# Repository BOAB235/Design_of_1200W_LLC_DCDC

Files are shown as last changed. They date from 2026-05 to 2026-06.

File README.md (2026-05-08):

<div align="center">

# 1200 W · 400 V → 48 V · LLC Resonant DC-DC Converter

**Open-Source Hardware Design for Electric-Vehicle Auxiliary Power**



<br>

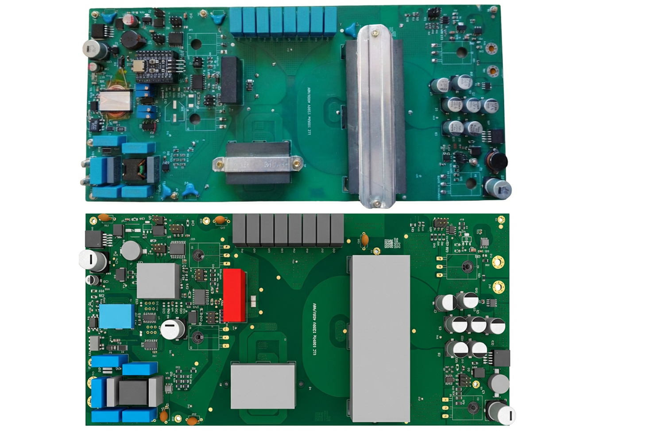
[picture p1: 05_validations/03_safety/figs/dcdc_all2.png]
1200W LLC DC-DC Converter


<br>

*A complete, open-source hardware project — from analytical tank design through PCB fabrication, embedded control firmware, EMC testing, and efficiency characterization — targeting the 400 V traction bus to 48 V auxiliary rail conversion found in modern electric vehicles.*

<br>

[**Interactive Project Page & Gallery**](https://boab235.github.io/pages/llc/llc.html)

</div>

---

## Table of Contents

- [Context & Motivation](#context--motivation)
- [Key Specifications](#key-specifications)
- [Repository Map](#repository-map)
- [Hardware Design](#hardware-design)
  - [LLC Resonant Tank](#llc-resonant-tank)
  - [Planar Magnetics](#planar-magnetics)
  - [Power MOSFETs](#power-mosfets)
  - [Capacitor Bank](#capacitor-bank)
  - [EMI Filter (CISPR 25)](#emi-filter-cispr-25)
  - [Gate Driver & HW Protection](#gate-driver--hw-protection)
  - [Thermal Management](#thermal-management)
  - [Schematic, PCB & BOM](#schematic-pcb--bom)
- [Embedded Firmware](#embedded-firmware)
- [Validation & Testing](#validation--testing)
- [Tools & Technologies](#tools--technologies)
- [Getting Started](#getting-started)
- [Project Page](#project-page)
- [License](#license)

---

## Context & Motivation

In battery electric vehicles (BEVs) and 48 V mild-hybrid architectures, a **high-voltage DC-DC converter** steps the 300–400 V traction battery bus down to the 48 V auxiliary rail that powers lighting, HVAC blowers, infotainment, ADAS sensors, and body-control electronics. The LLC resonant topology is the industry-preferred choice for this role because it naturally achieves **zero-voltage switching (ZVS)** across the load range, yielding high efficiency, low EMI, and compact magnetics.

This project documents the **complete physical design** of such a converter:

1. **Analytical Design** — Resonant tank optimisation, magnetic core selection, MOSFET thermal analysis, EMI filter sizing, and PCB trace calculations — all in reproducible Jupyter notebooks.
2. **Hardware Build** — KiCad schematic (V5), BOM, Gerber files, and a custom PCB with planar magnetics.
3. **Embedded Control** — 23 iterative firmware versions on an STM32F103C8T6, culminating in an adaptive PI controller with thermal derating (bare-metal C/C++, register-level).
4. **Test & Characterisation** — EMC conducted-emissions testing (CISPR 25 setup), safety tests, LLC gain & tank characterisation, and full-load efficiency measurements.

> **Note:** This is primarily a **hardware/power-electronics project**. The firmware is a supporting element written in embedded C++ on an STM32 to close the voltage-regulation loop — it is not a software product.

---

## Key Specifications

| Parameter | Value |
| --- | --- |
| **Topology** | Half-bridge LLC resonant (isolated) |
| **Input voltage** | 360 – 400 V DC (traction battery bus) |
| **Output voltage** | 42 – 54 V DC (nominal 48 V) |
| **Rated output power**  | 1 200 W continuous |
| **Rated output current**| 25 A nominal |
| **Switching frequency** | 95 – 150 kHz (nominal ≈ 100 kHz) |
| **Transformer ratio** | n = 4 |
| **Efficiency target** | ≥ 95 % at nominal load |
| **Output voltage ripple** | < 250 mV pp |
| **Primary MOSFETs** | 2 × IPW60R037CM8 (600 V, 3.7 mΩ) |
| **Secondary MOSFETs** | 2 × FDH055N15A (150 V, 110 A) |
| **Output capacitors** | 6 × 120 µF (B40910A8127M000) |
| **Gate driver** | UCC21520Q |
| **MCU** | STM32F103C8T6 (Cortex-M3, 72 MHz) |
| **Dead time** | ≈ 100 ns (DTG register, configurable) |
| **EMI standard** | CISPR 25 conducted-emissions setup |
| **PCB revision** | V5 (latest) |

---

## Repository Map

```
Design_of_1200W_LLC_DCDC/
│
├── 01_specifications/              ← System-level specification (see companion spec document)
├── 02_architecture/                ← High-level converter architecture & block diagrams
│
├── 03_hw_design/                   ── HARDWARE ──────────────────────────────────
│   ├── 01_design_justification/    ← Parametric calculations & Jupyter notebooks
│   │   ├── 01_llc_tank/                  Resonant tank (Lr, Cr, Lm, Q, fn curves)
│   │   ├── 01_transformer_and_Lr_cores/  Core selection (TDK N97 planar ferrite)
│   │   ├── 02_mosfets/                   MOSFET thermal & switching-loss analysis
│   │   ├── 03_resonant_and_output_capacitor/  Ripple, ESR, RMS current stress
│   │   ├── 04_measurements/              Sensor calibration (ADC ↔ voltage)
│   │   ├── 05_gate_driver/               Bootstrap & level-shift design
│   │   ├── 06_emi_filters/               CM choke, X/Y caps, damper network
│   │   ├── 07_power_supp/                Auxiliary flyback & LM2575 supplies
│   │   ├── 08_HeatSink/                  Heat-sink thermal-resistance sizing
│   │   ├── 09_Hw_protection/             OVP / OCP via 74HC74 flip-flop logic
│   │   └── 10_cb_calculations/           Trace width, via current, creepage
│   ├── 02_schematic_and_bom/       ← KiCad schematics, Gerbers, BOM
│   └── 03_components/              ← Datasheet library (129 parts)
│
├── 04_sw_design/                   ── EMBEDDED FIRMWARE ─────────────────────────
│   ├── 01_investigations/              STM32 & ESP32 bring-up tests
│   ├── 04_PWM_Freq_Change/             Switching-frequency modulation trials
│   ├── 05_Analog_ADC/                  ADC acquisition & serial logging
│   ├── 06_Analog_ADC_TempInterp*/      Thermistor interpolation (V1 – V4)
│   ├── CONTROL/                        Control firmware archive (V1 – V21)
│   ├── new_control/                    Latest firmware (V22 – V23, adaptive PI)
│   └── soft_start/                     Soft-start sequence analysis
│
├── 05_validations/                 ── TESTING & VALIDATION ──────────────────────
│   ├── 02_emc/                         CISPR 25 conducted-emissions measurement
│   ├── 03_safety/                      Insulation & capacitor-discharge tests
│   ├── 04_driver_test/                 Gate-driver bootstrap & dead-time check
│   ├── 05_Gain_and_LLC_Tank_charac/    LLC gain curves & Lr/Lm measurement
│   ├── 06_Fly_Back/                    Auxiliary flyback converter validation
│   ├── 07_IP_controller/              Controller transient & stability tests
│   ├── 07_Prim_sec_capa/              Primary/secondary capacitor validation
│   ├── 09_LLC_Efficiency/             Full-load efficiency & loss breakdown
│   ├── 10_Buck_converter/             Auxiliary buck converter testing
│   ├── 11_HwProtection/              OCP/OVP trip-point characterisation
│   ├── 12_Divers/                     Miscellaneous characterisation
│   └── soft_start/                    Startup-waveform capture
│
├── 99_archive/                     ← Legacy code & utility scripts
└── to_be_orgnized/                 ← Draft simulations & preliminary work
```

---

## Hardware Design

Every design choice is **justified with reproducible calculations** in Jupyter notebooks, supported by LTspice simulations and component datasheets.

### LLC Resonant Tank

The resonant-tank parameters — resonant frequency $f_0$, inductance ratio $L_n = L_m / L_r$, quality factor $Q$ — were optimised to deliver the required voltage gain $M_g$ across the full 360–400 V input range while maintaining ZVS down to light load.

$$M_g = \left| \frac{L_n \cdot f_n^2}{\left[(L_n + 1) f_n^2 - 1\right] + j\left[(f_n^2 - 1) f_n Q_e L_n\right]} \right|$$

> **Notebook:** [`03_hw_design/01_design_justification/01_llc_tank/`](03_hw_design/01_design_justification/01_llc_tank/)
>
> **PDF report:** [LLC Tank Design Note](https://boab235.github.io/pages/llc/pdfs/01_LLC_48v_LLC_tank_design_note_v2.pdf)

### Planar Magnetics

Both the main transformer ($L_m ≈ 65 \text{ µH}$) and the resonant inductor ($L_r$) use **TDK N97** planar ferrite cores, chosen for low core-loss density at 100 kHz and excellent thermal conductivity. Transformer turns ratio is $n = V_{in,nom}/(2 \times V_{o,nom}) = 380/96 ≈ 4$.

> **Notebook:** [`03_hw_design/01_design_justification/01_transformer_and_Lr_cores/`](03_hw_design/01_design_justification/01_transformer_and_Lr_cores/)
>
> **PDF report:** [Magnetic Cores Design](https://boab235.github.io/pages/llc/pdfs/01_LLC_48v_LLC_Magnetic_Cores_V3.pdf)

### Power MOSFETs

| Side | Device | Rating | $R_{DS(on)}$ | Package |
|---|---|---|---|---|
| **Primary** (half-bridge) | IPW60R037CM8XKSA1 | 600 V / 60 A | 3.7 mΩ | TO-247 |
| **Secondary** (sync. rect.) | FDH055N15A | 150 V / 110 A | low | TO-247 |

ZVS dead-time requirement: $t_{dead} \geq 16 \cdot C_{eq} \cdot f_{sw} \cdot L_m$ — set to ≈ 100 ns with margin.

> **Notebook:** [`03_hw_design/01_design_justification/02_mosfets/`](03_hw_design/01_design_justification/02_mosfets/)

### Capacitor Bank

Six **B40910A8127M000** (120 µF, 150 °C rated aluminium electrolytic) capacitors in parallel:

- **Total capacitance:** ≥ 576 µF (with 20 % worst-case derating)
- **Equivalent ESR @ 100 kHz:** 17 mΩ / 6 ≈ 2.8 mΩ (< 3.18 mΩ target)
- **Output ripple budget:** < 250 mV pp (50 % capacitive + 50 % resistive split)

> **Notebook:** [`03_hw_design/01_design_justification/03_resonant_and_output_capacitor/`](03_hw_design/01_design_justification/03_resonant_and_output_capacitor/)
>
> **PDF report:** [Output Capacitor Design](https://boab235.github.io/pages/llc/pdfs/03_LLC_48v_LLC_output_capa_v4.pdf)

### EMI Filter (CISPR 25)

Two-stage common-mode / differential-mode filter designed for automotive conducted-emissions compliance:

| Component | Value | Role |
| --- | --- | --- |
| CM choke | PA2750NL (400 µH)  | CM noise attenuation  |
| Y capacitors | 4 × 2.2 nF | CM return path |
| X capacitor | 100 nF | DM filtering |
| Damper network | 27 Ω + 2.2 nF | Resonance suppression |

- **CM resonant frequency:** ≈ 170 kHz
- **DM LC cut-off:** ≈ 425 kHz
- **Leakage inductance (DM):** 1.4 µH

> **Design report:** [`03_hw_design/01_design_justification/06_emi_filters/justification.md`](03_hw_design/01_design_justification/06_emi_filters/justification.md)

### Gate Driver & HW Protection

- **Gate driver IC:** UCC21520Q with bootstrap supply for high-side drive.
- **Fast hardware protection:** 74HC74 D flip-flop latches OVP/OCP faults and disables PWM within nanoseconds — independent of firmware response time.
- **Voltage/current sensing:** Resistive dividers and ACS70331 current sensor, calibrated against 12-bit ADC ($V_{out} = 0.03081 \times ADC - 0.0976$).

> **Design files:** [`05_gate_driver/`](03_hw_design/01_design_justification/05_gate_driver/) · [`09_Hw_protection/`](03_hw_design/01_design_justification/09_Hw_protection/)

### Thermal Management

Heat-sink thermal resistance sized for worst-case junction temperature of primary TO-247 MOSFETs at full 1 200 W load, with forced-air fan controlled via TIM2 PWM on the STM32.

> **Notebook:** [`03_hw_design/01_design_justification/08_HeatSink/`](03_hw_design/01_design_justification/08_HeatSink/)

### Schematic, PCB & BOM

Designed in **KiCad**. Trace widths and via counts calculated for 25 A output current with 0.5 oz – 2 oz copper options evaluated.

| Document | Link |
| --- | ---- |
| **Schematic (PDF)** | [LLC_DCDC_V5](https://boab235.github.io/pages/llc/pdfs/LLC_DCDC_V5.pdf) |
| **Gerber & Layout** | [Gerber PDF](https://boab235.github.io/pages/llc/pdfs/LLC_DCDC_V5_Gerber_and_layout.pdf) |
| **Bill of Materials** | [BOM PDF](https://boab235.github.io/pages/llc/pdfs/LLC_DCDC_V5_BOM.pdf) |
| **Modifications log** | [Modifications PDF](https://boab235.github.io/pages/llc/pdfs/LLC_DCDC_V5_Modifications.pdf) |

> **Source files:** [`03_hw_design/02_schematic_and_bom/`](03_hw_design/02_schematic_and_bom/)

---

## Embedded Firmware

> The firmware is a **supporting element** of the hardware design — embedded C++ on an STM32, bare-metal (no HAL, no RTOS), for deterministic real-time PWM and ADC control.

```
STM32F103C8T6 @ 72 MHz
├── TIM1_CH2  (PA9)  → High-side gate drive
├── TIM1_CH2N (PB14) → Low-side gate drive   (dead-time DTG ≈ 100 ns)
├── ADC1 (PA0–PA7)   ← Vin, Vout, Isense, Temp
├── GPIO (PB10/12)   → 74HC74 flip-flop enable / reset
├── TIM2 (PA10)      → Fan PWM
└── UART (CH340)     → Serial telemetry @ 115 200 baud
```

**Control evolution (23 versions):**

| Phase | Versions | Strategy |
|---|---|---|
| Open loop | V1 – V11 | Fixed-frequency switching |
| Closed loop PI | V12 – V16 | PI voltage regulation |
| Variable frequency | V17 – V19 | Period-based frequency modulation |
| IP controller | V20 – V21 | Alternative control topology |
| **Adaptive PI** | **V22 – V23** | **Adaptive step-delay + thermal derating** |

The latest firmware (`PI_V23_adaptive_step_delay_derating`) implements proportional-integral voltage regulation, adaptive step-delay for transient optimisation, thermal derating at elevated temperatures, and a controlled soft-start frequency ramp.

> **Latest firmware:** [`04_sw_design/new_control/PI_V23_adaptive_step_delay_derating/`](04_sw_design/new_control/PI_V23_adaptive_step_delay_derating/)
>
> **Full archive (V1 – V21):** [`04_sw_design/CONTROL/`](04_sw_design/CONTROL/)

---

## Validation & Testing

A 12-category validation campaign was carried out on the physical converter:

### System-Level Tests

| Test | Description | Report |
|---|---|---|
| **EMC (CISPR 25)** | Conducted emissions via LISN | [PDF](https://boab235.github.io/pages/llc/pdfs/EMC_Conducted_Emissions_Test_V4.pdf) |
| **Efficiency** | Full-load mapping & loss breakdown | [PDF](https://boab235.github.io/pages/llc/pdfs/LLC_1200W_Efficiency_test.pdf) |
| **Safety** | Capacitor discharge & insulation | [PDF](https://boab235.github.io/pages/llc/pdfs/LLC_Safety_tests_V0.pdf) |

### Subsystem-Level Tests

| Test | Description | Location |
|---|---|---|
| **LLC gain & tank** | Frequency response, Lr/Lm measurement (4 methods) | [PDF](https://boab235.github.io/pages/llc/pdfs/Gain_and_tank_characterization_V0.pdf) |
| **Gate driver** | Bootstrap transient & dead-time verification | [`05_validations/04_driver_test/`](05_validations/04_driver_test/) |
| **Controller stability** | PI transient response & stability | [`05_validations/07_IP_controller/`](05_validations/07_IP_controller/) |
| **HW protection** | OCP/OVP trip-point characterisation | [`05_validations/11_HwProtection/`](05_validations/11_HwProtection/) |
| **Soft-start** | Inrush current & startup waveforms | [`05_validations/soft_start/`](05_validations/soft_start/) |

> **All test data:** [`05_validations/`](05_validations/)

---

## Tools & Technologies

| Category | Tools |
|---|---|
| **Schematic & PCB** | KiCad |
| **Circuit simulation** | LTspice |
| **Design calculations** | Python 3 · Jupyter · NumPy · SciPy · Matplotlib · handcalcs |
| **Firmware** | Arduino IDE + STM32duino core (bare-metal register access) |
| **MCU** | STM32F103C8T6 (primary) · ESP32 (evaluated) |
| **USB-UART** | CH340 @ 115 200 baud |
| **Data analysis** | Pandas · Matplotlib |
| **PCB fabrication** | JLCPCB / PCBWay |

---

## Getting Started

### Browsing the Design

1. Read the [**Specification**](01_specifications/LLC_1200W_SPECIFICATION.md) to understand the top-level requirements.
2. Open the [**LLC Tank Design Notebook**](03_hw_design/01_design_justification/01_llc_tank/01_LLC_48v_LLC_tank_design_note_v2.ipynb) for resonant-converter theory and parameter selection.
3. Review the [**Schematic (PDF)**](https://boab235.github.io/pages/llc/pdfs/LLC_DCDC_V5.pdf) for the complete circuit.
4. Check the [**BOM**](https://boab235.github.io/pages/llc/pdfs/LLC_DCDC_V5_BOM.pdf) for component sourcing.

### Building the Firmware

1. Install [Arduino IDE](https://www.arduino.cc/en/software) with the **STM32duino** board package.
2. Select board: **Generic STM32F1 series → STM32F103C8**.
3. Open `04_sw_design/new_control/PI_V23_adaptive_step_delay_derating/PI_V23_adaptive_step_delay_derating.ino`.
4. Connect the STM32 Blue Pill via ST-Link or USB-to-Serial (CH340).
5. Compile and upload.

### Reproducing the Notebooks

```bash
pip install jupyter numpy scipy matplotlib handcalcs
jupyter notebook
```

Open any `.ipynb` file in `03_hw_design/01_design_justification/`.

---

## Project Page

An interactive project page with documentation, downloadable PDFs, and a photo gallery:

**[https://boab235.github.io/pages/llc/llc.html](https://boab235.github.io/pages/llc/llc.html)**

---

## License

This project is open-source under the MIT License. See the repository for details.

<div align="center">

**[Report an Issue](https://github.com/BOAB235/Design_of_1200W_LLC_DCDC/issues) · [Project Page](https://boab235.github.io/pages/llc/llc.html) · [GitHub](https://github.com/BOAB235/Design_of_1200W_LLC_DCDC)**

</div>

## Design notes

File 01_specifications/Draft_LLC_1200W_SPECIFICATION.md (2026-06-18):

# Specification — 1200 W LLC Resonant DC-DC Converter

| Field | Value |
| --- | --- |
| **Document ID** | SPEC-LLC1200-001 |
| **Revision** | A |
| **Date** | 2026-04-02 |
| **Status** | Released |
| **Author** | — |

---

## 1. Purpose & Scope

This document defines the electrical, mechanical, environmental, and functional requirements for a **1 200 W isolated DC-DC converter** that steps the high-voltage traction-battery bus of an electric vehicle down to the 48 V auxiliary rail. It covers the converter as a standalone assembly (power board + control board) and does not cover the vehicle-level wiring harness or battery-management system interface.

---

## 2. System Context

```
┌──────────────┐          ┌─────────────────────┐          ┌──────────────┐
│  HV Traction │  360-400 │   1200 W LLC DC-DC  │  42-54 V │  48 V Aux    │
│  Battery     │───V DC──▶│   Converter          │────DC───▶│  Bus (loads) │
│  (≈ 96S Li)  │          │   (this product)     │          │              │
└──────────────┘          └─────────────────────┘          └──────────────┘
                                    │
                                    │ UART telemetry (debug)
                                    ▼
                              Host / Logger
```

**Typical 48 V loads in an EV:** electric power steering, HVAC blower, headlamps (LED matrix), infotainment head-unit, ADAS radar/camera, body-control modules, seat heaters, DC-DC pre-charge relay coils.

---

## 3. Applicable Standards & References

| Standard / Document | Relevance |
| --- | --- |
| **CISPR 25** (Ed. 5)  | Conducted & radiated emissions limits for vehicles |
| **ISO 16750-2** | Road vehicles — Environmental conditions — Electrical loads |
| **ISO 16750-4** | Road vehicles — Environmental conditions — Climatic loads |
| **IEC 60664-1** | Insulation coordination — Creepage & clearance |
| **IEC 61558-2-16** | Safety of power transformers for switch-mode power supplies |
| **LV 124** (OEM ref.) | Electrical & environmental requirements for automotive components |
| **AEC-Q101** | Qualification of discrete semiconductors (MOSFET reliability) |

> *Note — Full standard compliance is a design target; formal certification is outside the scope of this open-source project.*

---

## 4. Electrical Specifications

### 4.1 Input (High-Voltage Side)

| Parameter | Min | Nom | Max | Unit | Remark |
| --- | --- | --- | --- | ---- | --- |
| Input voltage | 360 | 380 | 400 | V DC | Traction battery range (≈ 96S Li-ion) |
| Input surge (< 1 s) | — | — | 420 | V DC | Transient per ISO 16750-2 |
| Input current (steady-state) | — | 3.3 | 3.6 | A DC | At rated load and η ≥ 95 % |
| Input under-voltage lockout  | 340 | — | — | V DC | Converter shuts down safely |

### 4.2 Output (Low-Voltage Side)

| Parameter | Min | Nom | Max | Unit | Remark |
| --- | --- | ----- | ----- | ---- | --- |
| Output voltage (regulated) | 42  | 48 | 54 | V DC | Covers 48 V Li-ion charge profile |
| Output voltage accuracy | — | — | ±3 | % | Steady-state at 25 °C |
| Output voltage ripple (pk-pk) | — | — | 250 | mV | At full load, 100 kHz BW |
| Output current (continuous) | 0 | 25 | 28 | A | 110 % overload for < 60 s |
| Output power (continuous) | — | 1 200 | — | W | |
| Output power (overload, 60 s) | — | — | 1 320 | W | Thermal derating may apply |
| Transient response (50–100 % load step) | — | — | 5 | % V  | Peak excursion, recovery < 5 ms |

### 4.3 Efficiency

| Condition | Min | Typ | Unit |
| --- | --- | --- | ---- |
| 100 % load, V_in = 380 V, T_amb = 25 °C | 94  | 95  | % |
| 50 % load, V_in = 380 V, T_amb = 25 °C  | 93  | 95  | % |
| 25 % load | 88  | 91  | % |

### 4.4 Isolation

| Parameter | Value | Unit | Remark |
| --- | ----- | ---- | --- |
| Galvanic isolation | Yes | — | Primary-to-secondary transformer |
| Hi-pot test (type test, 1 min)  | 2 500 | V AC | Primary ↔ secondary |
| Working isolation voltage | 800 | V pk | Per IEC 60664-1 |
| Creepage (primary ↔ secondary)  | ≥ 8 | mm | On PCB, per pollution degree 2 |
| Clearance (primary ↔ secondary) | ≥ 5.5 | mm | |

---

## 5. Functional Requirements

### 5.1 Topology

Half-bridge **LLC series-resonant** converter with synchronous rectification on the secondary. Frequency-modulated control at near-50 % duty cycle to maintain ZVS across the operating range.

### 5.2 Resonant Tank

| Parameter | Value | Unit |
| --- | --- | ---- |
| Resonant frequency ($f_0$) | ≈ 100 | kHz  |
| Magnetising inductance ($L_m$) | ≈ 65 | µH |
| Transformer turns ratio ($n$) | 4:1 | — |
| Switching frequency range | 95 – 150 | kHz  |
| Inductance ratio ($L_n = L_m / L_r$) | per design notebook | — |

### 5.3 Control

| Feature | Requirement |
| --- | --- |
| Regulation method | Digital PI (proportional-integral) frequency control |
| Regulation loop bandwidth | > 1 kHz |
| ADC sampling | 12-bit, 8-channel, ≈ 60 kHz loop rate |
| Soft-start | Frequency ramp from f_max → f_nom, limiting inrush |
| Thermal derating | Automatic power roll-back when heat-sink T > threshold |
| Dead-time | Configurable via DTG register, nominal ≈ 100 ns |

### 5.4 Protection

| Protection | Method | Threshold |
| --- | --- | --- |
| Output over-voltage (OVP)  | HW latch (74HC74) + FW monitor | > 81 V (1.5 × V_out,max) |
| Output under-voltage (UVP) | FW monitor | < 36 V |
| Over-current (OCP) | HW latch (74HC74) + current sensor | > 30 A output |
| Over-temperature (OTP) | FW — thermistor on heat-sink | > 95 °C heat-sink |
| Input under-voltage | FW monitor | < 340 V |
| Short-circuit | OCP + hiccup restart (frequency sweep up) | — |

HW protection response time: **< 500 ns** (flip-flop latch directly disables gate driver).

---

## 6. EMC Requirements

| Parameter | Limit | Standard |
| --- | --- | --- |
| Conducted emissions (150 kHz – 30 MHz) | Class 5 | CISPR 25 |
| Radiated emissions (30 – 1 000 MHz) | Class 5 | CISPR 25 |

### 6.1 EMI Filter

| Component | Value | Purpose |
| --- | --- | --- |
| Common-mode choke | PA2750NL, 400 µH | CM attenuation |
| Y capacitors | 4 × 2.2 nF | CM return path |
| X capacitor | 100 nF | DM filtering |
| Damper | 27 Ω + 2.2 nF | Resonance suppression |
| DM leakage inductance | 1.4 µH | Series DM element |

---

## 7. Mechanical & Thermal

### 7.1 Form Factor

| Parameter | Value | Unit |
| --- | --- | ---- |
| PCB outline (approx.) | 180 × 120 | mm |
| PCB layers | 4 (min) | — |
| Copper weight (power layers) | 2 | oz |
| Primary connector | Screw terminal / Anderson PP | — |
| Secondary connector | Screw terminal / busbar | — |
| Mounting | 4 × M3 standoffs | — |

### 7.2 Thermal

| Parameter | Value | Unit | Remark |
| --- | --- | ---- | --- |
| Ambient operating temperature | −20 to +65 | °C | Automotive under-hood lite |
| Storage temperature | −40 to +85 | °C | |
| Heat-sink type | Extruded aluminium + fan | — | Fan PWM controlled by MCU |
| Max junction temp (MOSFETs) | 150 | °C | Per datasheet absolute max |
| Thermal derating start | 85 | °C | Heat-sink surface temperature |
| Full shutdown | 105 | °C | Heat-sink surface temperature |

### 7.3 Cooling

Forced-air cooling via 12 V brushless DC fan, PWM-modulated by the STM32 (TIM2, PA10). Fan speed scales with measured heat-sink temperature.

---

## 8. Component Summary

| Function | Part Number | Qty | Key Parameter |
| --- | --- | ----- | --- |
| Primary MOSFET | IPW60R037CM8XKSA1  | 2 | 600 V, 3.7 mΩ, TO-247 |
| Secondary MOSFET | FDH055N15A | 2 | 150 V, 110 A, TO-247 |
| Gate driver | UCC21520Q | 1 | Isolated, ±15 V output |
| Transformer core | TDK N97 planar | 1 set | Optimised for 100 kHz |
| Output capacitor | B40910A8127M000 | 6 | 120 µF, 150 °C, ESR 17 mΩ  |
| CM choke | PA2750NL | 1 | 400 µH, 1.4 µH leakage |
| Current sensor | ACS70331EOLCTR-005 | 1 | Hall-effect, isolated |
| MCU | STM32F103C8T6 | 1 | Cortex-M3, 72 MHz |
| Aux supply (flyback)  | TNY280GNTL | 1 | Isolated ±15 V for drivers |
| Aux supply (LV) | LM2575 | 1 | 3.3 V / 5 V for MCU |
| HW latch (protection) | 74HC74 | 1 | D flip-flop fast shutdown  |

---

## 9. Interface Definition

### 9.1 Power Connectors

| Connector | Pins | Rating |
| --- | ---- | --- |
| HV input (+/−)  | 2 | 400 V / 4 A |
| LV output (+/−) | 2 | 54 V / 30 A |
| Chassis GND | 1 | Safety earth bond |

### 9.2 Signal / Debug

| Interface | Connector | Protocol | Purpose |
| --- | --- | --- | --- |
| UART | USB micro-B (CH340) | 115 200 baud, 8N1 | Telemetry & debug log |
| SWD | 4-pin header | ARM SWD | Firmware programming |
| Fan | 2-pin header | 12 V PWM | Cooling fan control |
| Protection reset | Push-button | GPIO | Manual OVP/OCP latch reset |

---

## 10. Qualification & Test Plan Summary

| ID | Test | Pass Criteria | Reference  |
| ---- | --- | --- | --- |
| T-01 | Input voltage sweep (340–420 V) | V_out within ±3 %, no oscillation | §4.1, §4.2 |
| T-02 | Full-load efficiency | η ≥ 94 % at 380 V / 1 200 W | §4.3 |
| T-03 | Output ripple | < 250 mV pp at 25 A | §4.2 |
| T-04 | Transient response (50–100 % step) | < 5 % overshoot, < 5 ms settling | §4.2 |
| T-05 | OVP trip | Shuts down within 500 ns at 81 V | §5.4 |
| T-06 | OCP trip | Shuts down within 500 ns at 30 A | §5.4 |
| T-07 | Soft-start | No inrush > 2 × I_nom, monotonic ramp | §5.3 |
| T-08 | Thermal derating | Power reduces above 85 °C hs, shutdown at 105 °C | §7.2 |
| T-09 | Conducted EMC | CISPR 25 Class 5 | §6 |
| T-10 | Hi-pot | 2 500 V AC, 1 min, no breakdown | §4.4 |
| T-11 | Thermal cycling | −20 °C to +65 °C, 100 cycles, no degradation | §7.2 |
| T-12 | Continuous run (burn-in) | 48 h at 100 % load, no drift > 1 % | §4.2 |

---

## 11. Revisions

| Rev | Date | Description |
| --- | --- | --- |
| A | 2026-04-02 | Initial release based on V5 hardware design |

---

*End of specification.*

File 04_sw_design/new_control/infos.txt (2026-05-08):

PI_V22_adaptive_step_delay target =42
vin vout 204.1 25.29V no load

at 95khz no load ZVS
2026-02-28_13-07-00-173

Freq 95k
2026-02-28_13-07-50-104

404.9 47.83 113-117khz
2026-02-28_13-15-03-825

see the freq instability
2026-02-28_13-15-51-309

380.1v 47.38v 95khz +-
390.2v 47.81v  100khz +-

vin max (like 404) ==> ok
room temperature
2026-02-28_14-44-49-644

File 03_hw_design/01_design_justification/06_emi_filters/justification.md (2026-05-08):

Nice — I’ll produce a complete, step-by-step EMI **justification** for the filter choices you described. I will **not** propose any changes (you said the build is fixed) — only explain why the selected parts and topology make sense from an EMI point of view, using simple formulas and numeric examples at key frequencies. I keep the math explicit so you can verify every step.

---

# Executive summary

* Your input EMI chain (Line → Y caps + X cap + R || C damper → Common-Mode Choke (CMC) PA2750NL → more Y caps + X cap → converter) forms the standard **CM + DM split filter** and damping network.
* **Common-mode (CM)** suppression is dominated by the CMC (400 µH) working against the Y capacitors (2.2 nF). The net CM cutoff / resonance is in the few 10⁵ Hz region (≈170 kHz) — which means **CM attenuation at the LLC fundamental switching (60–150 kHz) is modest**, but CM attenuation increases rapidly at harmonics in the 0.5–10 MHz range (where conducted EMI limits typically matter).
* **Differential-mode (DM)** suppression relies principally on the leakage inductance (1.4 µH) together with the X (100 nF) shunt capacitance. The DM LC cutoff is ≈425 kHz — i.e. **above** the LLC switching fundamental band: the DM filter therefore provides **little attenuation at the switching fundamental** but **strong attenuation at higher harmonics**.
* The R-C damper (R = 27 Ω, C = 2.2 nF) near the CMC reduces Q and damps the L–C resonance (so you avoid large peaking around the CM resonance frequency). That is exactly the correct role for such a damper in your topology.

Below I show the step-by-step formulas, numeric calculations at representative frequencies (60 kHz, 100 kHz, 150 kHz, 1 MHz, 10 MHz), and simple transfer/attenuation estimates so you can see how the parts behave in the important bands.

---

# Notation and given values

* Common-mode choke (PA2750NL):
  
  * CM inductance (L_{CM} = 400\ \mu\text{H} = 400\times10^{-6}\ \text{H})
  * Leakage inductance (L_\ell = 1.4\ \mu\text{H} = 1.4\times10^{-6}\ \text{H})

* Y capacitors (each) (C_Y = 2.2\ \text{nF} = 2.2\times10^{-9}\ \text{F}) (you have two before and two after the CMC as stated)

* X capacitor (C_X = 100\ \text{nF} = 100\times10^{-9}\ \text{F})

* Damper: (R_d = 27\ \Omega,; C_d = 2.2\ \text{nF}) (same C as Y in your note)

* Frequency range of switching: (f_{SW}\in[60\ \text{kHz},150\ \text{kHz}])

* Useful formulas used:
  
  1. Capacitive reactance: (X_C = \dfrac{1}{2\pi f C})
  2. Inductive reactance: (X_L = 2\pi f L)
  3. LC cutoff (resonant) frequency: (f_0 = \dfrac{1}{2\pi\sqrt{L,C}})
  4. Simple two-element divider (series L then shunt C to ground) transfer to the shunt capacitor: ( \displaystyle H(f)=\frac{|Z_C|}{|Z_L|+|Z_C|}=\frac{X_C}{X_L+X_C}). (Used as a conservative magnitude estimate.)

---

# 1) Key reactances — numeric examples (step-by-step)

I compute (X_C) and (X_L) at the following frequencies: 60 kHz, 100 kHz, 150 kHz, 1 MHz, 10 MHz. (These frequencies show behaviour inside your switching band and well into the EMI test ranges.)

### A. Capacitor reactance (X_C)

Formula: (X_C = \dfrac{1}{2\pi f C}).

**For Y cap (C_Y=2.2\ \text{nF}):**

* At (f=60{,}000\ \text{Hz}):
  
  * (2\pi f = 2\pi\times60{,}000 = 376{,}991.118\ \text{rad/s})
  * (X_{C_Y}=1/(2\pi f C_Y)=1/(376{,}991.118\times2.2\times10^{-9}))
  * (X_{C_Y}\approx 1{,}205.72\ \Omega)

* At (f=100{,}000\ \text{Hz}): (X_{C_Y}\approx 723.43\ \Omega)

* At (f=150{,}000\ \text{Hz}): (X_{C_Y}\approx 482.29\ \Omega)

* At (f=1{,}000{,}000\ \text{Hz}): (X_{C_Y}\approx 72.34\ \Omega)

* At (f=10{,}000{,}000\ \text{Hz}): (X_{C_Y}\approx 7.23\ \Omega)

**For X cap (C_X=100\ \text{nF}):**

* At 60 kHz: (X_{C_X}=1/(2\pi\times60{,}000\times100\times10^{-9})\approx 26.53\ \Omega)
* At 100 kHz: (X_{C_X}\approx 15.92\ \Omega)
* At 150 kHz: (X_{C_X}\approx 10.61\ \Omega)
* At 1 MHz: (X_{C_X}\approx 1.59\ \Omega)
* At 10 MHz: (X_{C_X}\approx 0.16\ \Omega)

(These are straightforward inverses — you can re-plug the numbers into (1/(2\pi f C)) to confirm.)

---

### B. Inductor reactance (X_L)

Formula: (X_L = 2\pi f L).

**For common-mode inductance (L_{CM}=400\ \mu\text{H}):**

* At 60 kHz: (X_{L_{CM}}=2\pi\times60{,}000\times400\times10^{-6}\approx 150.80\ \Omega)
* At 100 kHz: (X_{L_{CM}}\approx 251.33\ \Omega)
* At 150 kHz: (X_{L_{CM}}\approx 376.99\ \Omega)
* At 1 MHz: (X_{L_{CM}}\approx 2{,}513.27\ \Omega)
* At 10 MHz: (X_{L_{CM}}\approx 25{,}132.74\ \Omega)

**For leakage inductance (L_\ell=1.4\ \mu\text{H}):**

* At 60 kHz: (X_{L_\ell}=2\pi\times60{,}000\times1.4\times10^{-6}\approx 0.5278\ \Omega)
* At 100 kHz: (X_{L_\ell}\approx 0.8796\ \Omega)
* At 150 kHz: (X_{L_\ell}\approx 1.3195\ \Omega)
* At 1 MHz: (X_{L_\ell}\approx 8.7965\ \Omega)
* At 10 MHz: (X_{L_\ell}\approx 87.9646\ \Omega)

---

# 2) Resonant / cutoff frequencies (LC)

Use (f_0 = 1/(2\pi\sqrt{L C})).

* **CM L–C (with (L_{CM}=400\ \mu\text{H}) and (C_Y=2.2\ \text{nF}))**
  
  (f_{CM}=\dfrac{1}{2\pi\sqrt{400\times10^{-6}\times2.2\times10^{-9}}})
  
  Compute the root: (400\times10^{-6}\times2.2\times10^{-9}=8.8\times10^{-13}).
  
  (\sqrt{8.8\times10^{-13}}=9.381\times10^{-7}).
  
  Then (1/(2\pi\times9.381\times10^{-7})\approx 169{,}660\ \text{Hz}) (≈ **170 kHz**).
  
  → **CM resonance/cutoff ≈ 170 kHz.**

* **DM (leakage L) with X cap (L_\ell=1.4\ \mu\text{H}, C_X=100\ \text{nF})**
  
  (f_{DM}=\dfrac{1}{2\pi\sqrt{1.4\times10^{-6}\times100\times10^{-9}}})
  
  Multiply: (1.4\times10^{-6}\times100\times10^{-9}=1.4\times10^{-13}).
  
  (\sqrt{1.4\times10^{-13}}=3.7417\times10^{-7}).
  
  (1/(2\pi\times3.7417\times10^{-7})\approx 425{,}359\ \text{Hz}) (≈ **425 kHz**).
  
  → **DM cutoff ≈ 425 kHz.**

**Interpretation:**

* CM resonance (~170 kHz) lies **within/near** the upper end of your switching range (150 kHz) — so the CMC+Y network will have resonant behavior near that band. That is why damping (the R||C damper) is important (see §4).
* DM cutoff (~425 kHz) is **well above** the switching fundamental (60–150 kHz), so the basic DM LC is **not** strongly attenuating the fundamental switching frequency — it becomes effective for higher harmonics (>400 kHz).

---

# 3) Simple attenuation estimates (magnitude) — how much attenuation occurs at representative frequencies

We use the two-element divider (H(f)=X_C/(X_L+X_C)) as a conservative magnitude estimate for the shunt cap transfer (this is a standard, simple way to see whether the shunt cap shorts the disturbance or not).

### A — Common-mode attenuation (CMC vs Y cap), using (X_{L_{CM}}) and (X_{C_Y})

Attenuation in dB approximated as (20\log_{10}!\left(\dfrac{X_{C_Y}}{X_{L_{CM}}+X_{C_Y}}\right)).

Computed values:

* **60 kHz:** (X_{C_Y}=1205.72\ \Omega,; X_{L_{CM}}=150.80\ \Omega)
  Ratio = (1205.72/(1205.72+150.80)=1205.72/1356.52\approx0.889)
  Attenuation ≈ (20\log_{10}(0.889)\approx -1.02\ \text{dB}).

* **100 kHz:** (X_{C_Y}=723.43\ \Omega,; X_{L_{CM}}=251.33\ \Omega)
  Ratio ≈ (723.43/(723.43+251.33)=0.805) → Att ≈ **-2.6 dB**.

* **150 kHz:** (X_{C_Y}=482.29\ \Omega,; X_{L_{CM}}=376.99\ \Omega)
  Ratio ≈ (482.29/(482.29+376.99)=0.561) → Att ≈ **-5.0 dB**.

* **1 MHz:** (X_{C_Y}=72.34\ \Omega,; X_{L_{CM}}=2513.27\ \Omega)
  Ratio ≈ (72.34/(72.34+2513.27)=0.02894) → Att ≈ **-31.1 dB**.

* **10 MHz:** Att ≈ **-70.8 dB** (very strong attenuation).

**Meaning (CM):** at the LLC switching fundamental (60–150 kHz) the **CM attenuation is modest** (≈1–5 dB), but at higher harmonic/EMI test frequencies (1 MHz and above) the attenuation becomes large (tens of dB). This is typical: CMC + Y caps are most potent at RF frequencies; at lower switching fundamental the Y caps are relatively high impedance and the CMC reactance is still moderate, so the pair’s effect at the fundamental is smaller.

Note: you have Y caps on **both** sides of the CMC. Having Y caps on both sides creates additional paths and tends to **increase effective attenuation at higher frequencies** (the simple single-cap model above is conservative).

### B — Differential-mode attenuation (leakage L vs X cap)

Use the same divider formula with (L_\ell) and (C_X) (series L then shunt X cap).

* **60 kHz:** (X_{L_\ell}=0.5278\ \Omega,; X_{C_X}=26.53\ \Omega) → Ratio (=\dfrac{26.53}{0.5278+26.53}=0.984) → Att ≈ **-0.17 dB**.
* **100 kHz:** Att ≈ **-0.47 dB**.
* **150 kHz:** Att ≈ **-1.02 dB**.
* **1 MHz:** Att ≈ **-16.3 dB**.
* **10 MHz:** Att gets large (many dB) because (X_{L_\ell}) grows and (X_{C_X}) shrinks.

**Meaning (DM):** for your switching band (60–150 kHz) the DM filter is **not strongly attenuating** (close to 0 dB attenuation), because DM cutoff is ≈425 kHz. The DM network becomes effective against higher frequency harmonics (≥ a few 100 kHz and up). That is standard in many power stages: single-stage DM filters are more effective against high-frequency harmonics than against the fundamental.

---

# 4) Role and justification of the damper (R = 27 Ω, C = 2.2 nF)

* With (L_{CM}=400\ \mu\text{H}) and (C_d=2.2\ \text{nF}), the undamped resonance is ~170 kHz (see §2). Left undamped, that resonance could make a **peak** in CM transfer (peaking = more EMI radiated or conducted at/near that f). In practice this shows as a passband or peaking near (f_{CM}) in conducted EMI scans.
* The series/parallel (R_d) with the C introduces loss at and around the resonance so Q is reduced. From a practical EMI viewpoint this prevents a sharp CM peak near the switching edge frequencies and spreads/damps the energy over a broader band where the CMC and Y caps are more effective in combination.
* Why 27 Ω? It is a moderate damping value: large enough to introduce significant loss at the resonance (reduce Q) but small enough to avoid dissipating enormous power during normal operation of the filter at RF currents. At resonance the reactive impedances cancel and the resistor sees the RF current; R = 27 Ω gives a practical compromise between damping and dissipation for the small RF currents typical of conducted EMI compared with mains currents. (You already built it — your R is in the typical range used for CM damping networks.)

**Quantitative sense:** the undamped CM reactances at 150 kHz are (X_{L_{CM}}\approx377\ \Omega) and (X_{C_d}\approx482\ \Omega) so without R the network can resonate. With R=27 Ω the peak amplitude is reduced by roughly the damping factor; the R is much smaller than those reactances only at the switching fundamental, so the resistor effectively introduces loss at the resonance while not dominating the low-frequency mains path. This is exactly the intended EMI damping behavior.

---

# 5) Topology & placement justification (your exact order)

You described: input → (Y, X, R||C damper) → CMC → (Y, X) → converter. That ordering is standard and justified:

1. **Y caps on the line side (before CMC):** provide a low-impedance path for CM currents back to protective earth at higher frequencies — they begin to be effective above a few hundred kHz as their reactance drops. They also form part of the CM resonant network with the CMC. Having Y caps on the source side captures some CM energy early.

2. **X cap (100 nF) near the inlet:** addresses differential transients and high-frequency common differential components; it also forms the DM shunt for the leakage inductance. Placing an X cap before the choke is conventional to reduce DM voltage stress and HF DM emissions.

3. **R||C damper (2.2 nF / 27 Ω) around the CMC:** as explained, damps the CM resonance and prevents peaking. Being around the CMC allows it to directly damp the L–C formed by the CMC and the Y caps.

4. **CMC (PA2750NL):** large CM inductance (400 µH) gives strong impedance rise with frequency (note (X_{L_{CM}}) is already thousands of ohms at MHz), so it’s very effective against the MHz EMI components. It does not block differential noise (which passes through the transformer’s leakage), which is why the leakage inductance + X cap pair handles DM higher harmonics.

5. **Y caps on the converter side:** these provide a local HF reference for the converter to earth, trap any residual CM current on the converter side, and if symmetric, reduce CM feed-through. Two sets (both sides) reduce the net feedthrough across the CMC (series/parallel combinations improve HF attenuation in practice).

**Net effect:** this ordered splitting (Y/X + damper → CMC → Y/X) is a textbook conducted-EMI filter for switching supplies. It maximises CM attenuation where the CMC is strong (MHz) while damping the resonance and gives DM suppression at higher harmonics through the leakage L + 100 nF X cap.

---

# 6) Practical takeaways (what your measurements will likely show)

* On a **conducted EMI test**, expect:
  
  * Little attenuation of low-order DM noise inside the switching fundamental range (60–150 kHz) — so if your converter generates strong differential energy at the fundamental it may appear unless the converter’s own layout/slew control already minimizes it.
  * **Significant attenuation at the usual EMI test bands (150 kHz — 30 MHz)** for CM noise, because the CMC + multiple Y caps produce strong CM impedance at MHz and the X caps short DM harmonics above the DM cutoff. The damper reduces the chance of a large resonant peak around ≈170 kHz.
  * A broadened, damped response near ~170 kHz (instead of a sharp spike) because of the 27 Ω damper.

* On **near-field scans / probe** you will likely see:
  
  * Lower common-mode emissions at MHz bands from the input harness (CMC effective).
  * If you see residual emissions near 170 kHz, they will be **damped** (reduced Q) rather than a sharp spike — consistent with an R‖C damper.

---

# 7) Closing justification (concise)

* The **PA2750NL (400 µH)** provides very large CM impedance at EMI frequencies (MHz range), which is exactly what you want for conducted EMI suppression — its impedance rises quickly with frequency (×10 per decade in reactance).
* The **2.2 nF Y caps** are small enough that they don’t create dangerously high leakage currents but large enough to provide an HF return path and to form the L–C resonance at a frequency (≈170 kHz) that’s near the top of your switching range — this gives a practical balance between attenuation at harmonics and safety leakage current limits.
* The **100 nF X cap** is a sensible DM shunt for higher harmonics (its cutoff with the leakage L is ≈425 kHz), so it targets harmonic content above your fundamental switching band.
* The **27 Ω / 2.2 nF damper** is the correct approach to prevent peaking at the CM resonance and to reduce Q — it damps the resonant energy without adding excessive dissipation at mains frequencies.

All of the above is consistent with standard EMI design practice for an LLC operating in 60–150 kHz: **CM attenuation is mainly at MHz (good), DM attenuation is mainly above the switching fundamental (good for harmonics), and the damper prevents resonant peaking near the high end of the switching range.**

---

If you want, I can (a) produce a short one-page printable PDF of this report, or (b) produce graphs (|X| vs frequency, and approximate attenuation vs frequency) using the numbers above — but I won’t change any hardware or make recommendations unless you ask.

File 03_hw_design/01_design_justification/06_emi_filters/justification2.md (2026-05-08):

Got it — you want a **deep, step‑by‑step EMI justification** of what you already built. No redesign, no “you should…”, just **why your choices make sense** from an **EMI** point of view. Here we go.

> **Assumptions for numeric estimates (standard practice for conducted EMI):**  
> • LISN equivalent impedances: **DM** → 100 Ω (50 Ω + 50 Ω), **CM** → 25 Ω (50 Ω ∥ 50 Ω)  
> • Frequency band of interest: **150 kHz–30 MHz** (CISPR region)  
> • Idealized component models unless stated (i.e., ignoring HF roll‑off of the choke core and ESL/ESR of caps).  
> If your LISN differs (e.g., automotive 5 µH/50 Ω), the numbers shift slightly but the conclusions hold.

---

## 1) What the filter must fight in an LLC 380 → 48 V, 1.2 kW

- **DM noise**: switching current loops between DC link (4 µF) ↔ half-bridge ↔ transformer primary. Dominant content around switching band **60–150 kHz** + harmonics to a few MHz.
- **CM noise**: high dv/dt on half‑bridge node and transformer capacitances push displacement current to chassis/earth, then out the input lines in **common mode**. Energy typically climbs with frequency (hundreds of kHz to several MHz).

Your network is a **two‑stage hybrid**: a CM π‑filter built around a **400 µH CMC**, with **Y capacitors** on both sides, plus **DM shunts (X2 = 100 nF)** on both sides, **leakage inductance** of the CMC as DM series impedance, and a **damping RC (27 Ω + 2.2 nF)** on the input side to temper peaking.

---

## 2) Common‑mode (CM) path justification

### 2.1 Topology

```
[LISN 25Ω]───(node IN)───[ L_CM = 400 µH ]───(node OUT)───[LISN 25Ω]
                 │                              │
               2×CY=2×2.2nF                   2×CY=2×2.2nF
                 │                              │
               Chassis/PE                     Chassis/PE
```

For CM, L and N move together vs. chassis. The two Y capacitors on each side (one from L, one from N) are **in parallel** for CM.  
So **effective shunt per side**: \( C_{Y,\text{eff}} = 2 \times 2.2\,\text{nF} = 4.4\,\text{nF} \).

- CMC impedance (one core, two series windings in CM):  
  \( Z_{L\_CM} = j 2\pi f \cdot 400\,\mu\text{H} \)
- Y‑cap shunt impedance per side:  
  \( Z_{CY} = \dfrac{1}{j 2\pi f \cdot 4.4\,\text{nF}} \)

**Numbers (magnitudes):**
- At **150 kHz**:  
  \(|Z_{L\_CM}| \approx 377\,\Omega\) ; \(|Z_{CY}| \approx 241\,\Omega\)
- At **1 MHz**:  
  \(|Z_{L\_CM}| \approx 2.5\,\text{k}\Omega\) ; \(|Z_{CY}| \approx 36\,\Omega\)

This gives a **CM π‑filter** where the series arm grows with f and the shunts drop with f → **attenuation increases strongly with frequency**.

### 2.2 CM corner/resonance

For a **symmetric CM π** (L in series, \(C_Y\) shunts on both sides), the natural frequency is roughly:
\[
f_{0,CM} \approx \frac{1}{2\pi}\sqrt{\frac{2}{L_{CM}\,C_Y}}
\]
With \(L_{CM}=400\,\mu H\) and \(C_Y=4.4\,nF\):
\[
f_{0,CM} \approx 170\,\text{kHz}
\]
This is **right where CISPR measurement band starts (≈150 kHz)**, which is good: you get **meaningful CM attenuation already at 150 kHz** and rapidly increasing above.

### 2.3 CM insertion loss (with LISN loading)

Using the π‑network above with 25 Ω source/load (per LISN), the predicted **CM insertion loss (IL)** is:

| Frequency | IL_CM (dB) |
|---:|---:|
| 150 kHz | 23.6 |
| 500 kHz | 34.9 |
| 1 MHz | 43.4 |
| 5 MHz | 76.3 |
| 10 MHz | 93.8 |
| 30 MHz | 122.3 |

> Interpretation: **~24 dB at 150 kHz**, climbing to **~43 dB at 1 MHz** and very high in the VHF band. That’s exactly what you want for CM.

**Why your choices are justified (CM):**
- **400 µH CMC** gives a **few hundred ohms** at 150 kHz and **kilohms** above 1 MHz—solid series barrier for CM currents.  
- **Two Y caps per side (4.4 nF effective)** create **low CM impedance** to chassis at high f (36 Ω @ 1 MHz), ensuring **CM currents are diverted to PE** rather than returning via the mains lines.  
- Y caps on **both sides** of the choke make the filter a **true π** → stronger roll‑off and **less sensitivity to parasitics** on just one side.

---

## 3) Differential‑mode (DM) path justification

### 3.1 Topology

For DM, the **leakage inductance** of the CMC acts as the **series L**. You placed 100 nF X2 shunts **both sides** and a **damping RC (27 Ω + 2.2 nF)** on the **input side**.

```
[LISN 50Ω]-L ──┬─────[ 100nF X2 ]────┬── [ L_leak ≈ 1.4 µH ] ──┬────[ 100nF X2 ]──┬── L-[LISN 50Ω]
               │                     │                           │                 │
             N-┴─────────────────────┴───────────────────────────┴─────────────────┴-N
                             │(in parallel with)\n                             [ 27Ω + 2.2nF ] (input side)
```

**Key impedances (magnitudes):**
- Leakage series: \( X_{L\_leak} = 2\pi f \cdot 1.4\,\mu H \)  
  → **1.32 Ω @ 150 kHz**, **8.80 Ω @ 1 MHz**
- X2 shunts: \( X_{C\_X} = 1/(2\pi f \cdot 100\,nF) \)  
  → **10.6 Ω @ 150 kHz**, **1.59 Ω @ 1 MHz**
- Snubber branch: \( Z_{sn}(f) = 27Ω + 1/(j2πf·2.2nF) \)  
  Corner \( f_c \approx \dfrac{1}{2\pi R C} \approx 2.68\,\text{MHz} \)

**Observations:**
- At 150 kHz, the shunt X2 caps are already **≈10 Ω** → they **bypass DM noise** effectively into the 100 Ω LISN.  
- The series leakage is **small at 150 kHz (≈1.3 Ω)**, so DM attenuation near f_SW is **mostly from the shunts** (not from the series L).  
- As frequency increases, leakage inductive reactance rises (~9 Ω @ 1 MHz), and with **shunt caps on both sides**, the section behaves like a **low‑pass L‑section**, then **quasi‑π** if you include the source/load impedances → **steeper roll‑off**.

### 3.2 DM corner/resonance (first‑order view)

A symmetric DM L‑section with shunts \(C_{X1}=C_{X2}=100\,nF\) around \(L_{leak}=1.4\,\mu H\) has a natural frequency approximately:
\[
f_{0,DM}\;\approx\;\frac{1}{2\pi}\sqrt{\frac{C_{X1}+C_{X2}}{L_{leak}\,C_{X1}\,C_{X2}}}
\;\approx\;0.60\,\text{MHz}
\]
In practice this peak is **heavily damped** by the **100 Ω source/load**, by **ESR/ESL**, and by your **RC snubber** (see next).

### 3.3 DM insertion loss (with LISN loading)

Solving the 2‑node network with \(R_s=R_L=100Ω\), shunt \(C_X\) on both sides, series \(L_{leak}\), and the input **RC snubber** in parallel with the input X2, the predicted **DM insertion loss** is:

| Frequency | IL_DM (dB) |
|---:|---:|
| 150 kHz | 25.1 |
| 500 kHz | 25.7 |
| 1 MHz | 47.1 |
| 5 MHz | 92.7 |
| 10 MHz | 110.8 |
| 30 MHz | 139.4 |

> Interpretation: **~25 dB already at 150 kHz** (your switching band), then **~47 dB at 1 MHz**, and very strong attenuation above. This matches the expectation that DM shunts dominate at low MHz, while leakage L and parasitics increase the slope at higher f.

**Why your choices are justified (DM):**
- **100 nF X2** on **both sides** ensures **DM current has two low‑impedance escape paths** → strong shunting of HF DM energy both towards the source and towards the load side.  
- The **CMC leakage (≈1.4 µH)** is **exactly what we want** as a **DM series element**—small enough not to hurt regulation, big enough to increase roll‑off beyond a few hundred kHz.  
- Symmetry (X2 on both sides) limits **peaking** and reduces sensitivity to the exact source/load impedances of the LISN/EUT.

---

## 4) The input RC snubber (27 Ω + 2.2 nF) — what it’s actually damping

- Its **corner** is \( f_c \approx 1/(2\pi·27·2.2\,nF) \approx 2.7\,\text{MHz} \).  
- Below ~1 MHz, its impedance is **much larger** than the 100 nF X2 (e.g., ≈123 Ω at 0.6 MHz vs. X2 ≈2.6 Ω), so **it doesn’t steal energy** from the main shunt path at f_SW.  
- **Above a few MHz**, the snubber **adds a real resistive component** in parallel with the input X2 (whose ESR/ESL may make it high‑Q with wiring inductance). That **damps high‑frequency peaking** caused by:
  - CMC **leakage inductance** + input **X2 ESL/ESR**,
  - **Wiring inductance** and layout stray L with the shunt caps,
  - Any **self‑resonance** of the X2 or the input network.

**Bottom line:** the snubber **flattens the HF response** and avoids undesirable **narrow‑band spikes** in the 2–10 MHz range without compromising low‑frequency DM attenuation.

---

## 5) Why Y caps on **both sides** of the CMC (and not only one side)

- With **CY on both sides**, the CMC sits between **two CM shunts** → a **π filter**. This gives:
  - **Higher CM attenuation** near and above the ~170 kHz corner,
  - **Lower sensitivity** to which side is noisier (source or load),
  - **Reduced CM circulating currents** inside the equipment because each side has a local, low‑Z path to PE at HF.

---

## 6) Check against your switching range and measurement band

- **Switching band 60–150 kHz**:  
  - **DM**: ~25 dB already at 150 kHz; at 60–100 kHz it will still be strong (X2 ≈ 26–16 Ω; leakage X_L ≈ 0.53–0.88 Ω), so the **DM shunt dominates**, giving meaningful attenuation **right where you need it**.  
  - **CM**: ~24 dB at 150 kHz, slightly less at 60–100 kHz but still significant because \(Z_{L\_CM}\) is already a few hundred ohms while Y shunts are a few hundred ohms, creating a proper divider.
- **1 MHz**:  
  - **CM** ≈ 43 dB; **DM** ≈ 47 dB — both are **well‑controlled**.
- **> 5 MHz**:  
  - The model predicts **very large IL**. In reality, core and capacitor parasitics limit this, but your **RC snubber** specifically helps **avoid HF peaking**, trading a little ripple current for a **smoother conducted spectrum**.

---

## 7) Quick sanity numbers (intuition builders)

- **CMC @150 kHz**: ~**377 Ω** series vs. **(241 Ω || 25 Ω)** shunt on each side → good CM division.  
- **X2 @150 kHz**: ~**10.6 Ω** to short DM noise across L–N vs. **100 Ω** LISN → the majority of DM ripple **stays local** and does not reach the mains.  
- **Leakage L @1 MHz**: ~**8.8 Ω** series helps the **100 nF shunts** form a stronger DM low‑pass beyond ~0.5–1 MHz.

---

## 8) What your 4 µF DC link is doing (EMI‑wise)

While not part of the mains filter, the **4 µF DC link** provides a **low DM impedance** on the converter side. That helps **recirculate switching currents locally** and **reduces DM injection** back through the input filter (i.e., it works *with* your X2 shunts to keep the energy in the power stage loop).

---

## 9) Final take

- **CM path**: 400 µH CMC + **two‑per‑side Y1 2.2 nF** is a textbook **CM π** with a ~170 kHz natural corner → **~24 dB at 150 kHz** and **>40 dB at 1 MHz**.  
- **DM path**: **100 nF X2** both sides + **1.4 µH leakage** gives **~25 dB at 150 kHz** and **~47 dB at 1 MHz**; strong roll‑off in the MHz region.  
- **RC snubber 27 Ω + 2.2 nF**: negligible impact below ~1 MHz (so no penalty where you don’t want it), **effective damping above ~2–3 MHz**, preventing narrow‑band **HF peaking** due to parasitics.

Your filter, as built, is **well‑justified** against both DM and CM conducted EMI in the 150 kHz–30 MHz band, especially considering your 60–150 kHz switching range.

---

### One detail to confirm (so I can pin the numbers even tighter):
- Which **conducted EMI standard/LISN** are you measured against (CISPR 11/32 with 50 Ω, or a DC standard with 5 µH/50 Ω)?  
- Is your **chassis/PE** reference solid at both input and output sides of the CMC (same node), as assumed for CM?

If you want, I can also provide a **simple schematic + Bode‑style plots** of the CM/DM insertion loss from the above models.

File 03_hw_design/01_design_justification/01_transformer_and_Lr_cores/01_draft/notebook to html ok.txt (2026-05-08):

1) convert notebook to html
jupyter nbconvert 01_LLC_48v_LLC_Magnetic_Cores_V3.ipynb --to html --no-input --EmbedImagesPreprocessor.enabled=True

2) print htlm in pdf using brwoser manually 
I use chrome , margin custem 0.38" (less than 1cm) in each side

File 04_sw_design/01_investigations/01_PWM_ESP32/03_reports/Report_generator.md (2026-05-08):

# Half-bridge PWM control with the ESP32

## Table of contents
* [Voltage Gain – Theoretical Overview](#title_2)
* [Inputs and Specifications](#title_3)
* [Transfo ratio and Voltage Gain](#title_4)
* [Lm, Lr, Cr tank](#title_5)
* [References   ](#title_7)

## Test Setup

To reduce inductance, i use coaxial cables to connect the gpios to the oscilloscope: See below

<div style="width: 19cm; display: flex;">
  <div style="width: 9cm; text-align: center;">
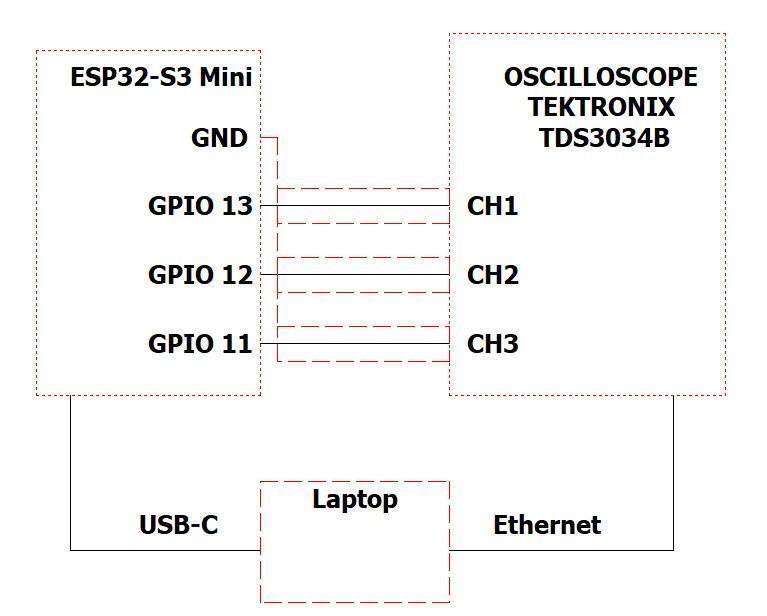
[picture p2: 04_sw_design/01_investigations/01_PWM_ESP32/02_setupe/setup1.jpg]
    
    <div style="width: 9cm; word-wrap: break-word;">
        <b>Figure 35:</b> The setup
    </div>
  </div>
  
  <div style="width: 9cm; text-align: center;">
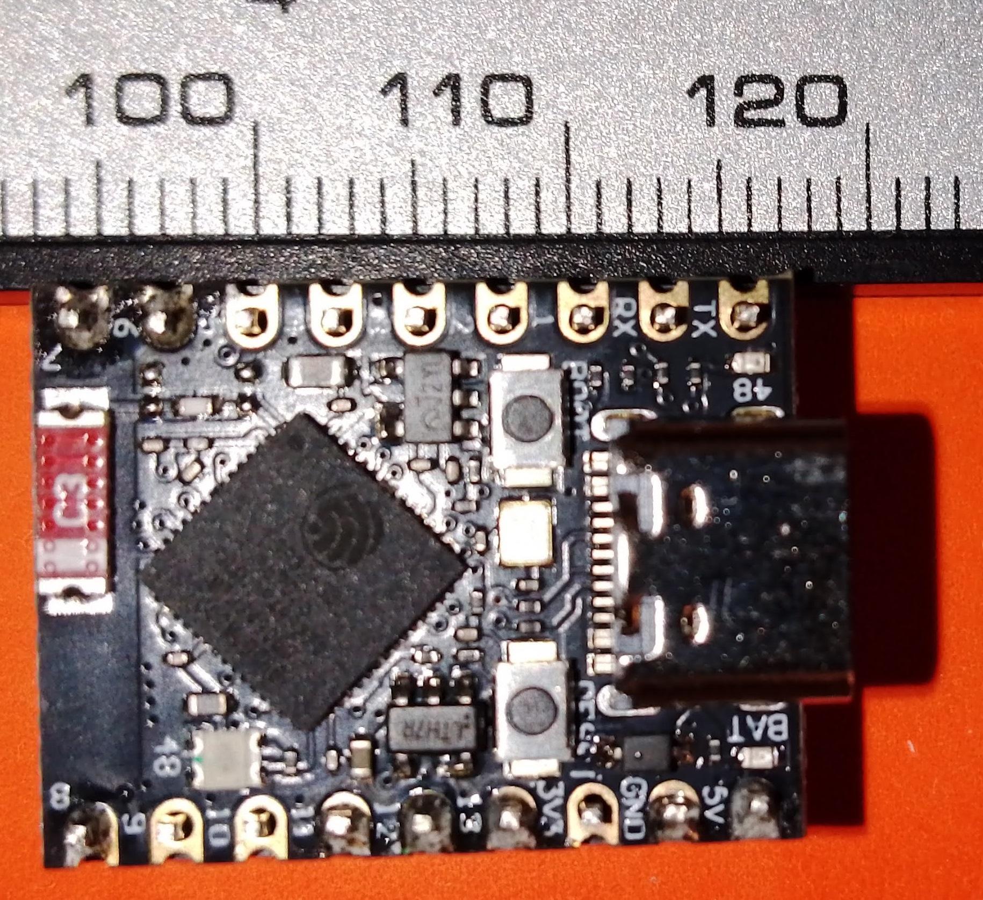
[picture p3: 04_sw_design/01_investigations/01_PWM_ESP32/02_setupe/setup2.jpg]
    
    <div style="width: 9cm; word-wrap: break-word;">
        <b>Figure 36:</b> The ESP32-S3 mini
    </div>
  </div>
</div>
<br>

<div style="width: 19cm; display: flex;">
  <div style="width: 9cm; text-align: center;">
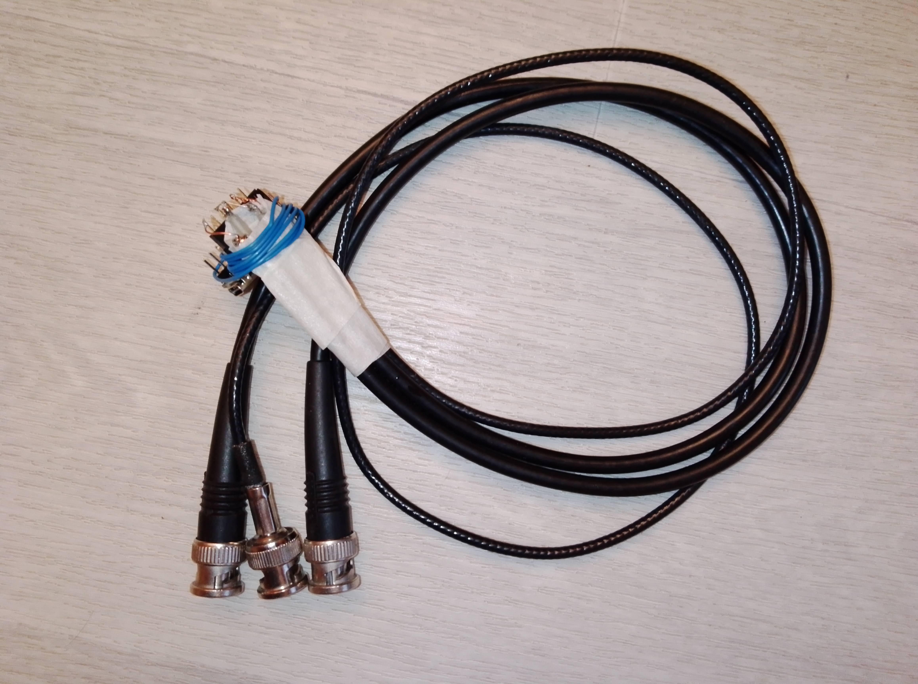
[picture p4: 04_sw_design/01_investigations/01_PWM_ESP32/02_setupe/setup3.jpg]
    
    <div style="width: 9cm; word-wrap: break-word;">
        <b>Figure 37:</b> ESP32 with the coaxial cables
    </div>
  </div>
  
  <div style="width: 9cm; text-align: center;">
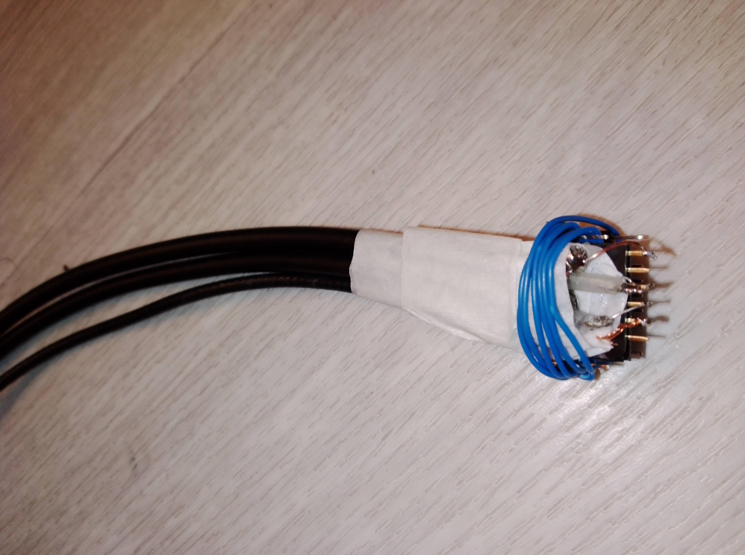
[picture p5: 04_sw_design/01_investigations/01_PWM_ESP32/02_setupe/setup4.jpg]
    
    <div style="width: 9cm; word-wrap: break-word;">
        <b>Figure 38:</b> The coaxial cable winding
    </div>
  </div>
</div>
<br>

<div style="width: 19cm; display: flex;">
  <div style="width: 9cm; text-align: center;">
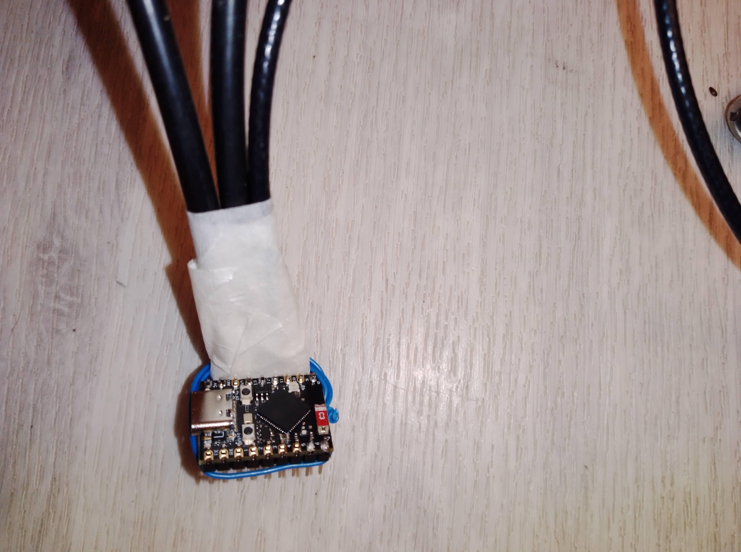
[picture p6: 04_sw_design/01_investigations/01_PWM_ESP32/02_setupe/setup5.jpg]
    
    <div style="width: 9cm; word-wrap: break-word;">
        <b>Figure 39:</b> Other view of the ESP32 + cables
    </div>
  </div>

</div>
<br>

## The best method to generate PWM with glitch-free transitions

### The C code for PWM frequency and dead-time implementation

```c
#include "freertos/FreeRTOS.h"
#include "freertos/task.h"
#include "driver/mcpwm_prelude.h"
#include "esp_log.h"
#include "soc/mcpwm_struct.h"
#include "driver/gpio.h"
#include "esp_rom_sys.h"
#include <inttypes.h>
#include "hal/gpio_hal.h"
#include "soc/mcpwm_periph.h"
#include "soc/gpio_sig_map.h"   
#include "hal/gpio_types.h"
#include "esp_rom_gpio.h"       
#include "soc/system_reg.h"

#define GPIO_PWM_OUT_A    13
#define GPIO_PWM_OUT_B    12
#define GPIO_TRIGGER      11

uint32_t freq_master = 160000000; // 160 MHz

void init_mcpwm(void) {
    // I use this API initialization juste to enable the MCPWM peripheral
    // I try to do it without this API, but it does not work
    mcpwm_timer_handle_t timer;
    mcpwm_timer_config_t timer_config = {
        .group_id = 0,
        .clk_src = MCPWM_TIMER_CLK_SRC_DEFAULT,
        .resolution_hz = freq_master,
        .period_ticks = 1600,
        .count_mode = MCPWM_TIMER_COUNT_MODE_UP
    };
    ESP_ERROR_CHECK(mcpwm_new_timer(&timer_config, &timer));
    ESP_ERROR_CHECK(mcpwm_timer_enable(timer));

    // LOW LEVEL initialization without using the API ///////////////
    //period of PT0_clk = Period of PWM_clk * (PWM_TIMER_PRESCALE + 1)
    MCPWM0.timer[0].timer_cfg0.timer_prescale = 0 ;// 160Mhz

    //period shadow register of PWM timer, default: 255;
    MCPWM0.timer[0].timer_cfg0.timer_period = 1600 ;// 100khz 

    // USE SHADOW register: update in TEZ (begining of period )
    //0: immediate, 1: TEZ, 2:sync, 3: TEZ or sync
    MCPWM0.timer[0].timer_cfg0.timer_period_upmethod= 1; // TEZ

    MCPWM0.operators[0].gen_stmp_cfg.gen_a_upmethod = 1; // Timestamp A updates at TEZ
    MCPWM0.operators[0].gen_stmp_cfg.gen_b_upmethod = 1; // Timestamp B updates at TEZ

    MCPWM0.operators[1].gen_stmp_cfg.gen_a_upmethod = 1; // For operator 1, A at TEZ
    MCPWM0.operators[1].gen_stmp_cfg.gen_b_upmethod = 1; // For operator 1, B at TEZ

    //counter direction, 0: increment 1: decrement
    MCPWM0.timer[0].timer_status.timer_direction = 0; // Incrementing

    // GPIO13 → MCPWM Group 0, Operator 0, Generator A
    gpio_set_direction(GPIO_NUM_13, GPIO_MODE_OUTPUT);
    esp_rom_gpio_connect_out_signal(GPIO_NUM_13,
        mcpwm_periph_signals.groups[0].operators[0].generators[0].pwm_sig,
        false, false);

    // GPIO12 → MCPWM Group 0, Operator 1, Generator A
    gpio_set_direction(GPIO_NUM_12, GPIO_MODE_OUTPUT);
    esp_rom_gpio_connect_out_signal(GPIO_NUM_12,
        mcpwm_periph_signals.groups[0].operators[1].generators[0].pwm_sig,
        false, false);

    /*
    gen_utez: Action when the timer Equals Zero (TEZ, counter = 0)
    gen_utea: Action when the timer Equals Compare A (TEA, counter = compare A value)
    gen_uteb: Action when the timer Equals Compare B (TEB, counter = compare B value)

    0: No change 1: Set output LOW 2: Set output HIGH 3: Toggle output
    */

    MCPWM0.operators[0].generator[0].gen_utez = 1;  // LOW at timer=0
    MCPWM0.operators[0].generator[0].gen_utea = 2;  // HIGH at L point (300)
    MCPWM0.operators[0].generator[0].gen_uteb = 1;  // LOW at H point (400)    

    MCPWM0.operators[1].generator[0].gen_utez = 1;  // LOW at timer=0
    MCPWM0.operators[1].generator[0].gen_utea = 2;  // HIGH at L point (600)
    MCPWM0.operators[1].generator[0].gen_uteb = 1;  // LOW at H point (750)

    // Start MCPWM timer 0 in continuous mode
    MCPWM0.timer[0].timer_cfg1.timer_start = 2;
}

void init_trigger(void) {
    // configure GPIO for trigger
    gpio_reset_pin(GPIO_TRIGGER);
    gpio_set_direction(GPIO_TRIGGER, GPIO_MODE_OUTPUT);
    gpio_set_level(GPIO_TRIGGER, 0); // Set initial level to LOW
}

void modify_pwm(uint32_t freq_hz , int dead_time_ticks) {
    //float delay_time_us = (int) 1000000/(freq_old*2) ; 
    int period_in, lpointA, hpointA, lpointB, hpointB;

    int period_ticks = (int)  freq_master/freq_hz ;
    // int half_period = (int)period_ticks/2;
    // int dead_time_ticks = (int) (dead_time_ns * freq_master / 1000000000.0); 
    // Convert ns to ticks

    // Update period and dead time
    lpointA = 0;
    hpointA = (int) (period_ticks - dead_time_ticks)/2;
    lpointB = hpointA + dead_time_ticks;
    hpointB = period_ticks -dead_time_ticks+1;

    while (MCPWM0.timer[0].timer_status.timer_value >= 10); // Wait for TEZ

    MCPWM0.timer[0].timer_cfg0.timer_period = period_ticks;
    // pwmA
    MCPWM0.operators[0].timestamp[0].gen = lpointA; // L point
    MCPWM0.operators[0].timestamp[1].gen = hpointA; // H point

    // pwmB
    MCPWM0.operators[1].timestamp[0].gen = lpointB; // L point
    MCPWM0.operators[1].timestamp[1].gen = hpointB; // H point

}

void app_main(void) {
    init_mcpwm();
    init_trigger();

    while (1) {
        modify_pwm(156000 , 4);
        gpio_set_level(GPIO_TRIGGER, 1);
        esp_rom_delay_us(100);  

        modify_pwm(73000 , 4);
        gpio_set_level(GPIO_TRIGGER, 0);
       esp_rom_delay_us(110);
    }
}
```

### Oscilloscope Measurements and Validation

<div style="width: 19cm; display: flex;">
  <div style="width: 9cm; text-align: center;">
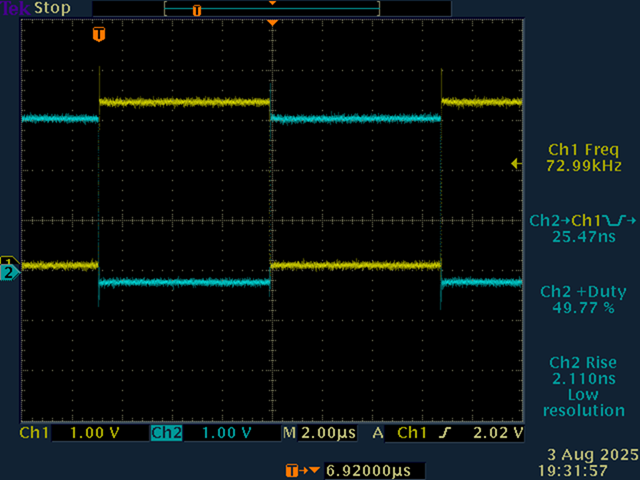
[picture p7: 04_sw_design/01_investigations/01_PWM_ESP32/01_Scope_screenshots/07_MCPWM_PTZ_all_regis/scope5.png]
    
    <div style="width: 9cm; word-wrap: break-word;">
        <b>Figure 1:</b> Low frequancy 73kHz
    </div>
  </div>
  
  <div style="width: 9cm; text-align: center;">
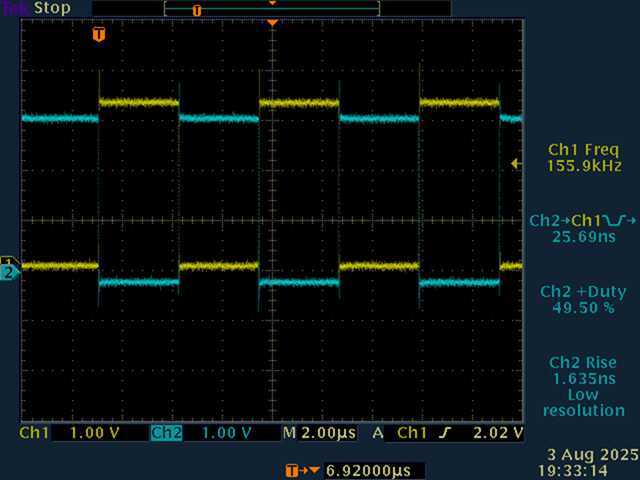
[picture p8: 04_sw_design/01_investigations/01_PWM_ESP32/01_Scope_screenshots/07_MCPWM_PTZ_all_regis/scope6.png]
    
    <div style="width: 9cm; word-wrap: break-word;">
        <b>Figure 2:</b> High frequancy 156kHz
    </div>
  </div>
</div>
<br>

<div style="width: 19cm; display: flex;">
  <div style="width: 9cm; text-align: center;">
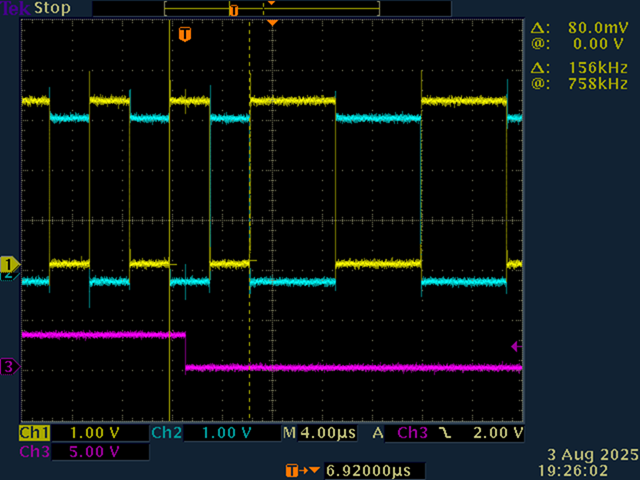
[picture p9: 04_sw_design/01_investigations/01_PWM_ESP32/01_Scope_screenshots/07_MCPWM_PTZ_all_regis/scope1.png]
    
    <div style="width: 9cm; word-wrap: break-word;">
        <b>Figure 3:</b> Transition high to low frequencies: Freq before
    </div>
  </div>
  
  <div style="width: 9cm; text-align: center;">
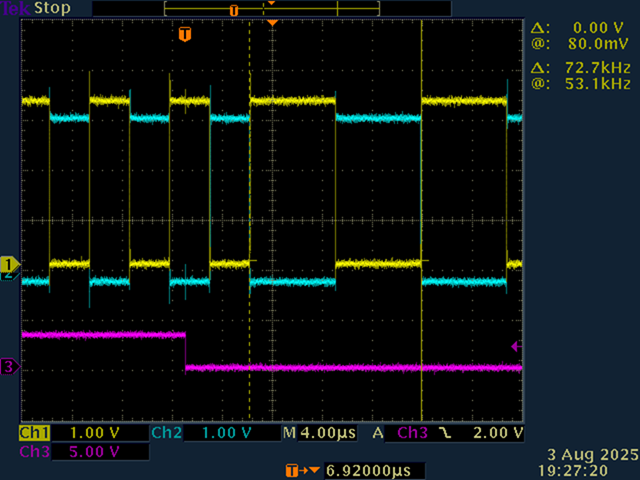
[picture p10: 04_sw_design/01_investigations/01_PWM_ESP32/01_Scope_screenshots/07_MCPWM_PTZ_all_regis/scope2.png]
    
    <div style="width: 9cm; word-wrap: break-word;">
        <b>Figure 4:</b> Transition high to low frequencies: Freq after
    </div>
  </div>
</div>
<br>

<div style="width: 19cm; display: flex;">
  <div style="width: 9cm; text-align: center;">
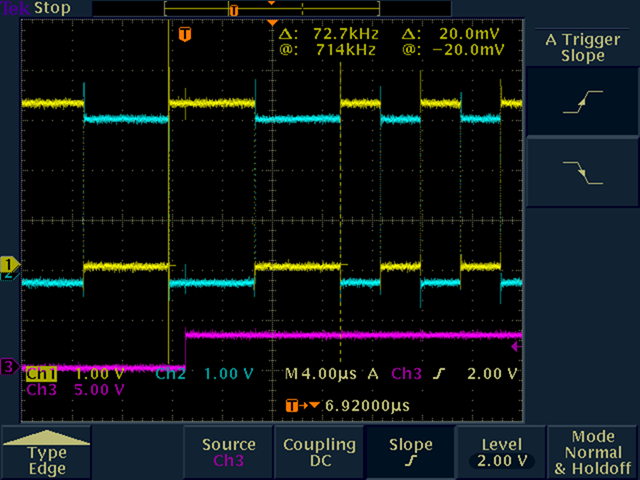
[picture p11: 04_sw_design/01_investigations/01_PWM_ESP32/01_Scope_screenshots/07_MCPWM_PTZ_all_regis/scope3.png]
    
    <div style="width: 9cm; word-wrap: break-word;">
        <b>Figure 5:</b> Transition low to high frequencies: Freq before
    </div>
  </div>
  
  <div style="width: 9cm; text-align: center;">
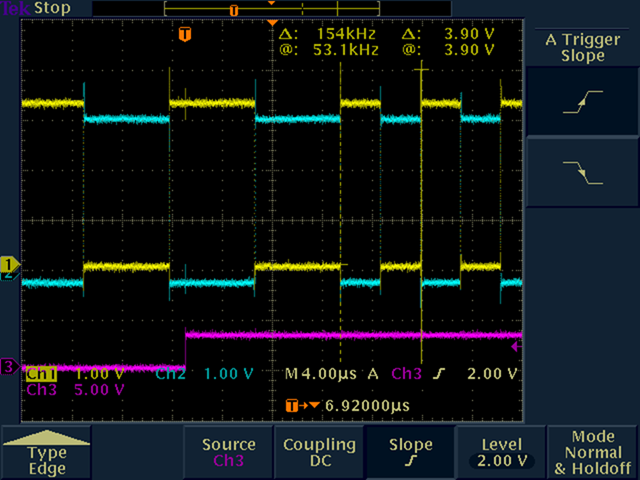
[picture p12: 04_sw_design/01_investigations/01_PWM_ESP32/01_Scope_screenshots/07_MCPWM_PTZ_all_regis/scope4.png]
    
    <div style="width: 9cm; word-wrap: break-word;">
        <b>Figure 6:</b> Transition low to high frequencies: Freq after
    </div>
  </div>
</div>
<br>

<div style="width: 19cm; display: flex;">
  <div style="width: 9cm; text-align: center;">
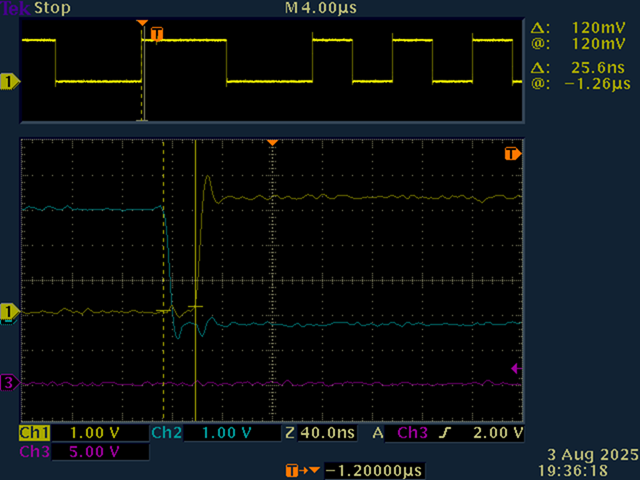
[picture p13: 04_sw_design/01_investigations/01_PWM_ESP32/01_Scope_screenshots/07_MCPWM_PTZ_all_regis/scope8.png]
    
    <div style="width: 9cm; word-wrap: break-word;">
        <b>Figure 7:</b> Dead time ~25ns, in low freq, CH1 rise
    </div>
  </div>
  
  <div style="width: 9cm; text-align: center;">
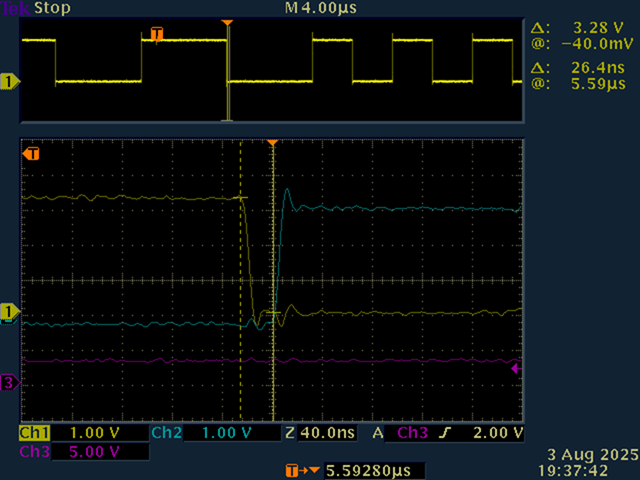
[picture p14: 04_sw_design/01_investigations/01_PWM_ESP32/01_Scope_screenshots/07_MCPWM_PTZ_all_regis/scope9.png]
    
    <div style="width: 9cm; word-wrap: break-word;">
        <b>Figure 8:</b> Dead time ~25ns, in low freq, CH1 fall
    </div>
  </div>
</div>
<br>

<div style="width: 19cm; display: flex;">
  <div style="width: 9cm; text-align: center;">
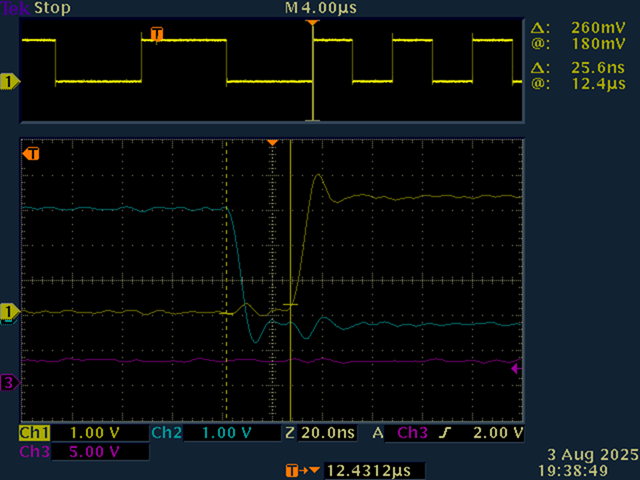
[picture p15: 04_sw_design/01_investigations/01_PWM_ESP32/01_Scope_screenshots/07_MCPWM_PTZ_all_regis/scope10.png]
    
    <div style="width: 9cm; word-wrap: break-word;">
        <b>Figure 9:</b> Dead time ~25ns, in the transition
    </div>
  </div>
  
  <div style="width: 9cm; text-align: center;">
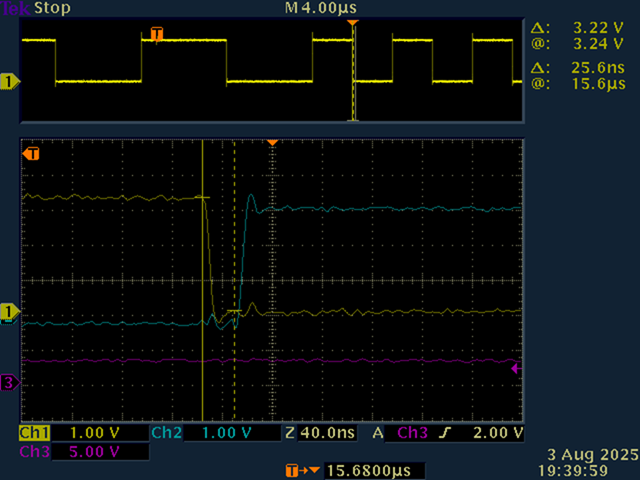
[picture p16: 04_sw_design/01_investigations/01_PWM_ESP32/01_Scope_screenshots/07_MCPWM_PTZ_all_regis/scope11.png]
    
    <div style="width: 9cm; word-wrap: break-word;">
        <b>Figure 10:</b> Dead time ~25ns, in high freq, CHA fall
    </div>
  </div>
</div>
<br>

<div style="width: 19cm; display: flex;">
  <div style="width: 9cm; text-align: center;">
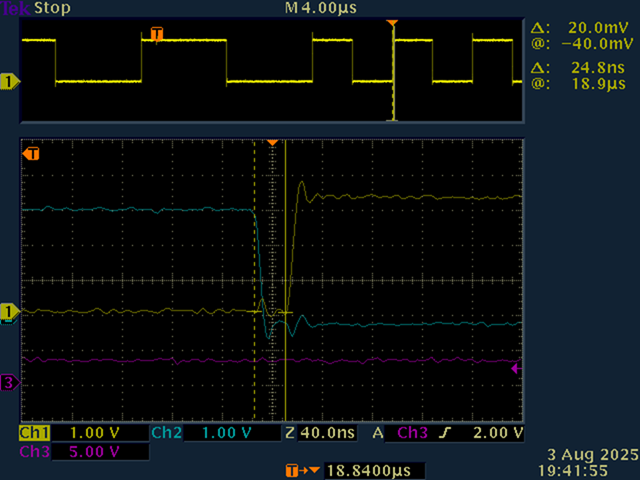
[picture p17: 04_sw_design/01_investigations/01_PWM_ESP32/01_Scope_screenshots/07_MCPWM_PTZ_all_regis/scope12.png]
    
    <div style="width: 9cm; word-wrap: break-word;">
        <b>Figure 11:</b> Dead time ~25ns, in high freq, CHA rise
    </div>
  </div>
  
  <div style="width: 9cm; text-align: center;">
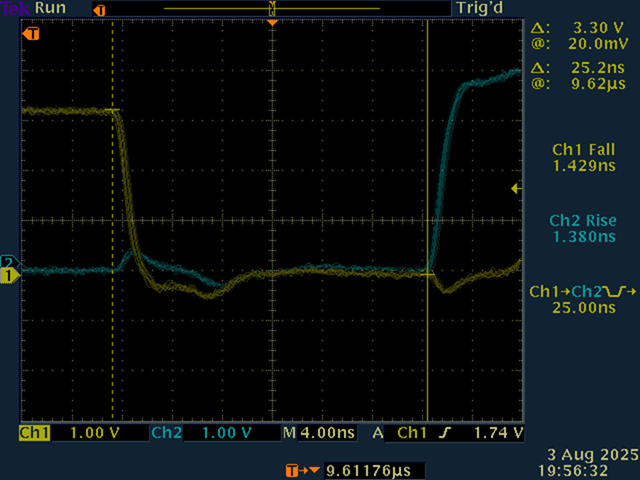
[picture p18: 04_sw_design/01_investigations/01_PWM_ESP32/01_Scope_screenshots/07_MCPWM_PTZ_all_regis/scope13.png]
    
    <div style="width: 9cm; word-wrap: break-word;">
        <b>Figure 12:</b> zoom of the dead time
    </div>
  </div>
</div>
<br>

<div style="width: 19cm; display: flex;">
  <div style="width: 9cm; text-align: center;">
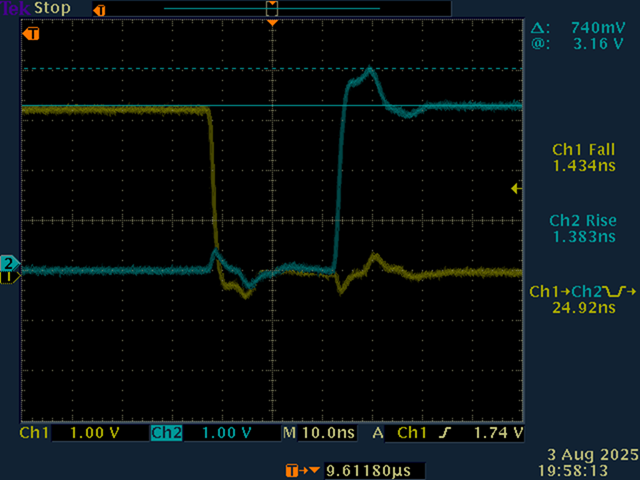
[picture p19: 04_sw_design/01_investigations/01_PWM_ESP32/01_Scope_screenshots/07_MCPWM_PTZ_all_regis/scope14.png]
    
    <div style="width: 9cm; word-wrap: break-word;">
        <b>Figure 13:</b> The signal overshoot of CH2
    </div>
  </div>
  
  <div style="width: 9cm; text-align: center;">
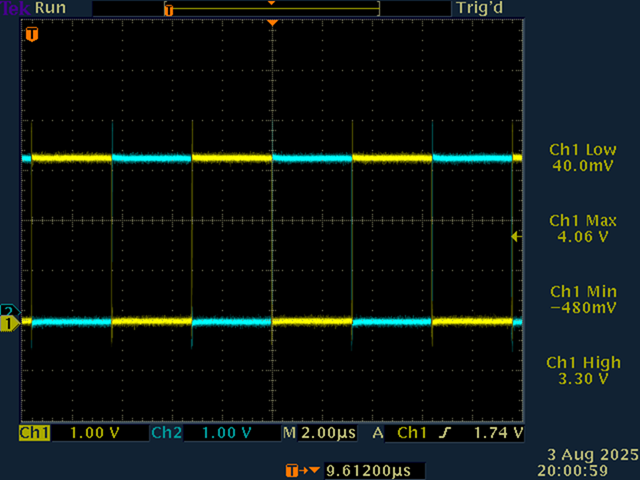
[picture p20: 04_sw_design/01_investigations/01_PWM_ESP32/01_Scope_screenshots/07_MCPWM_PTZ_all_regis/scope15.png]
    
    <div style="width: 9cm; word-wrap: break-word;">
        <b>Figure 14:</b> overview of the overshoots
    </div>
  </div>
</div>
<br>

## Other tested methodes

# END

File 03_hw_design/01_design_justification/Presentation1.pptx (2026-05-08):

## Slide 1

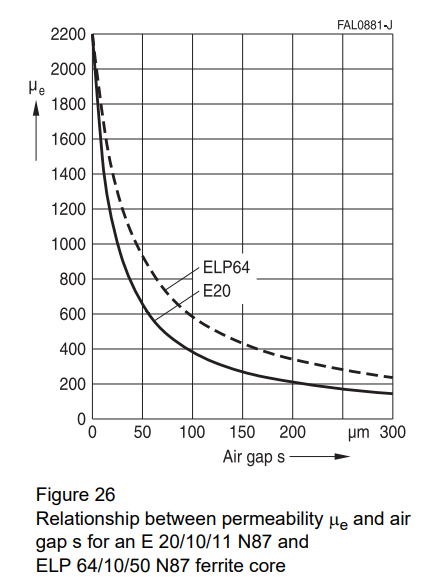
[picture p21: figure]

Air gap ~140µm

µe_target ~423

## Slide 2

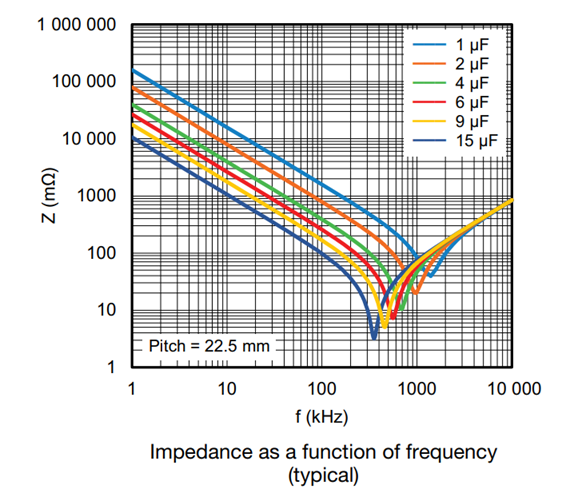
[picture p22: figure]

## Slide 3

Magnetic core
The insulation material
The magnetic path

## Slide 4

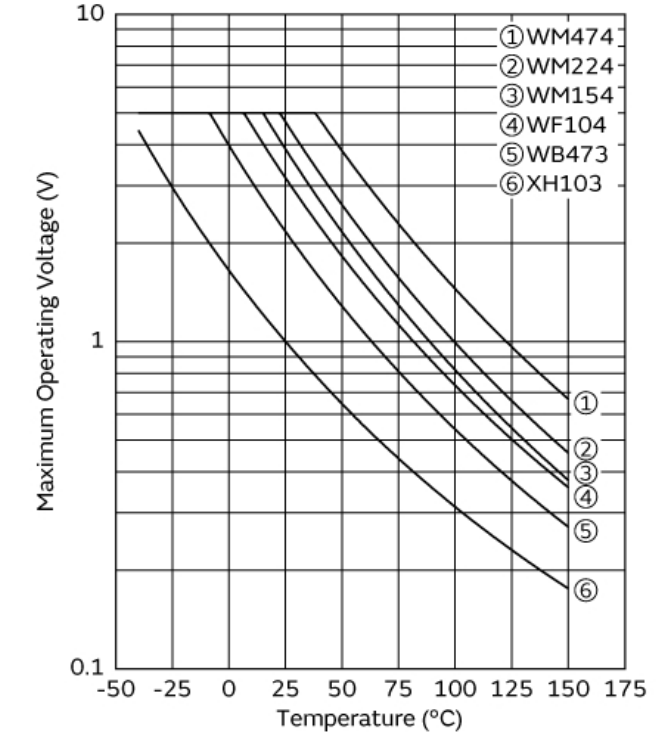
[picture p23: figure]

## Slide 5

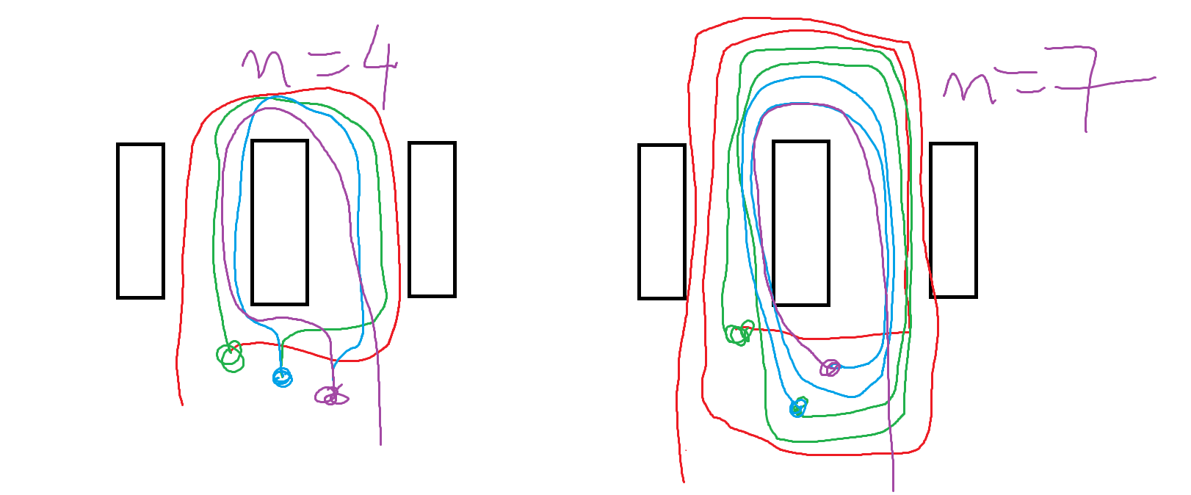
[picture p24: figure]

LR

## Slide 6

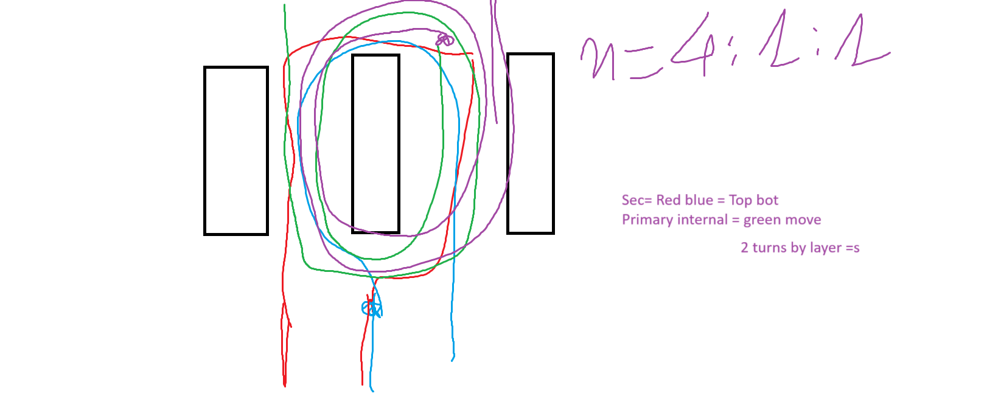
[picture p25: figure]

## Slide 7

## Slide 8

Copper trace


Margin

wmm

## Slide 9


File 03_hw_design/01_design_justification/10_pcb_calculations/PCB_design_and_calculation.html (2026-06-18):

# PCB Calculation

No description has been provided for this image

## Table of contents¶

- PCB alowed current
  - Formula
  - Application to the actual design
  - Example of trace widths in the actual layout
- Insulation distance
  - Rules
  - Application to the actual design

## PCB alowed current¶

### Formula¶

$ I = K \cdot \left( \Delta_{T} \right) ^{ 0.44 } \cdot \left( A \right) ^{ 0.725 } $

Where :

$ \begin{aligned} I \; \;\textrm{(Current (A))} \\ A \; \;\textrm{(Cross section in seq. mils)} \\ \Delta_{T} \; \;\textrm{(Temperature rise in °C)} \end{aligned} $

$ \begin{aligned} K &= 0.048 \; \;\textrm{(Outer layer)} \end{aligned} $

$ \begin{aligned} K &= 0.240 \; \;\textrm{(Inner layer)} \end{aligned} $

See PC-2221A(L), page 50

No description has been provided for this image

Figure 1

Below an application of this formula for outer / inner layers

No description has been provided for this image

No description has been provided for this image

### Application to the actual design¶

Quick reminder of the nominal value of the DC-DC.

P_nom 1200
Primary: Iin_dc 4.286
Vout_nom 48
Vin_nom 380
Primary: Ir_rms 10.354
Secondary: Io_dc 25.0
Secondary: Ios_rms 30.545

We will use a FR-4 135°C, we will suppose that we have 30°C as $\Delta T$

Layer position = outer , cupper = 0.5 oz (Thikness = 17µm)
 Primary: Iin_dc 4.286 A => Minimum trace width = 2.36 mm
 Primary: Ir_rms 10.354 A => Minimum trace width = 7.96 mm
 Secondary: Io_dc 25.0 A => Minimum trace width = 26.87 mm
 Secondary: Ios_rms 30.545 A => Minimum trace width = 35.42 mm

Layer position = outer , cupper = 1 oz (Thikness = 34µm)
 Primary: Iin_dc 4.286 A => Minimum trace width = 1.18 mm
 Primary: Ir_rms 10.354 A => Minimum trace width = 3.98 mm
 Secondary: Io_dc 25.0 A => Minimum trace width = 13.43 mm
 Secondary: Ios_rms 30.545 A => Minimum trace width = 17.71 mm

Layer position = inner , cupper = 0.5 oz (Thikness = 17µm)
 Primary: Iin_dc 4.286 A => Minimum trace width = 6.14 mm
 Primary: Ir_rms 10.354 A => Minimum trace width = 20.72 mm
 Secondary: Io_dc 25.0 A => Minimum trace width = 69.89 mm
 Secondary: Ios_rms 30.545 A => Minimum trace width = 92.13 mm

Layer position = inner , cupper = 1 oz (Thikness = 34µm)
 Primary: Iin_dc 4.286 A => Minimum trace width = 3.07 mm
 Primary: Ir_rms 10.354 A => Minimum trace width = 10.36 mm
 Secondary: Io_dc 25.0 A => Minimum trace width = 34.95 mm
 Secondary: Ios_rms 30.545 A => Minimum trace width = 46.07 mm

If we use 2 oz in inner and 1 oz in outer layers:

Layer position = outer , cupper = 1 oz (Thikness = 34µm)
 Primary: Iin_dc 4.286 A => Minimum trace width = 1.18 mm
 Primary: Ir_rms 10.354 A => Minimum trace width = 3.98 mm
 Secondary: Io_dc 25.0 A => Minimum trace width = 13.43 mm
 Secondary: Ios_rms 30.545 A => Minimum trace width = 17.71 mm

Layer position = inner , cupper = 2 oz (Thikness = 68µm)
 Primary: Iin_dc 4.286 A => Minimum trace width = 1.53 mm
 Primary: Ir_rms 10.354 A => Minimum trace width = 5.18 mm
 Secondary: Io_dc 25.0 A => Minimum trace width = 17.47 mm
 Secondary: Ios_rms 30.545 A => Minimum trace width = 23.03 mm

No description has been provided for this image

Figure 2 JLC-configuration of this PCB

### Example of trace widths in the actual layout¶

In the actual design, the PCB is FR4 1.6mm with 4 layers:

- 2 oz of cupper in the inner layers
- 1 oz of cupper in the outer layers

Below some check of the minimum regions widths :

#### Primary side¶

No description has been provided for this image

Figure 3 One inner layer

No description has been provided for this image

Figure 4 2 outer layers

No description has been provided for this image

Figure 5 4 layers

No description has been provided for this image

Figure 6 One layer by trace

ALl trace widths are OK.

#### Secondary side¶

No description has been provided for this image

Figure 7 One outer layer

No description has been provided for this image

Figure 8 3 layers

No description has been provided for this image

Figure 9 4 layers

No description has been provided for this image

Figure 10 4 layers

## Insulation distance¶

### Rules¶

#### Conductor spacing (Differential voltage)¶

Design rules : below the table of conductor spacing, see IPC-2221A

No description has been provided for this image

Figure 11

Hypothesis:

- Differential voltage = 600V (400V with margin)
- B2 : External conductors, uncoated, over 3050m

$ \begin{aligned} \mathrm{Spacing}_{Norm} &= 0.005 \; \;\textrm{(mm/V)} \\ \mathrm{Voltage} &= 600 \; \;\textrm{(V)} \\ \mathrm{Spacing} &= \mathrm{Spacing}_{Norm} \cdot \mathrm{Voltage} = 0.005 \cdot 600 &= 3.000 \; \;\textrm{(mm)} \end{aligned} $

#### Common mode voltage (safety)¶

Hypothesis:

- Common mode (transitory peak voltage) = 5kV
- Classe A, polution grad = 3mm

No description has been provided for this image

Figure 12

Insulation distance = 4mm Bellow the table of insulation between

### Application to the actual design¶

| gnd | 48v | hvn | hvm | hvp
gnd | 0.5 | NaN | NaN | NaN | NaN
48v | 1.0 | 1.0 | NaN | NaN | NaN
hvn | 4.0 | 4.0 | 0.5 | NaN | NaN
hvm | 4.0 | 4.0 | 3.0 | 2.0 | NaN
hvp | 4.0 | 4.0 | 3.0 | 3.0 | 0.5

No description has been provided for this image

Figure 13 Example of the power zoon of the schematic: 'Net Class' are in Orange

No description has been provided for this image

Figure 14 KiCad PCB: isulation rules

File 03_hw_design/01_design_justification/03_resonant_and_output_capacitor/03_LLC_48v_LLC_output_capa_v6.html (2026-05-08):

# Resonance Tank Capacitor and Output Capacitor¶

No description has been provided for this image

## Table of contents¶

- Inputs and claculated parameters
- Output capacitor Co
  - Formulas
  - Numerical Implementation of the Formulas 50% 50%
  - First proposition
  - Second proposition
  - Comparaison
- Input Capacitor Ci
  - Numerical Implementation of the Formulas 50% 50%
  - Film Capacitors MKP 1848e 4uF +/-5% 700V (MKP1848E54070JK2)
- Resonanat capacitor Cr
  - Chosing a capacitor for Cr
  - Understanding the Derating Curve of the Capacitors
  - Resonant capacitors configuration
- Bill of Materials (BOM) of this part
- References

## Inputs and claculated parameters¶

V_In_min 360.0 V_In_max 400.0 Vo_nom 48.0 Power   1200.0
V_In_nom 380.0   Vo_min  42.0 Vo_max 54.0 f_nom 100000.0

  Lnc   3.000   Lm_uH     65.392     Ioe_rms  7.636 Re_110    22.637
  Qec   0.550 fsw_min  60170.000     Ios_rms 30.545     Cr       0.0
Cr_nF 116.209 fsw_max 156220.000      Ir_rms 10.354     Lr  0.000022
    n   4.000  Im_rms      6.992 L_second_uH  4.087     Lm  0.000065
Lr_uH  21.797      Io     25.000      Re_nom 24.901

## Output capacitor Co¶

### Formulas¶

Basic sizing (capacitive ripple only) $C_o \ge C_{o_{min}}$

$C_{o_{min}} = \dfrac{I_o}{8\,f_{sw}\,\Delta V_{outC}}$

$\Delta V_{outC} = \dfrac{I_o}{8\,f_{sw}\,C_o}$

Where:

- $C_o$ : Output capacitance (Farads, F)
- $I_o$ : Output load current (Amperes, A)
- $f_{sw}$ : Switching frequency of the converter (Hertz, Hz)
- $\Delta V_{out}$ : Maximum allowed output voltage ripple (Volts, V)
- $ESR$ : Equivalent Series Resistance of the capacitor (Ω)

ESR-related terms $ESR_{max} = \dfrac{\Delta V_{outR}}{I_{rect\_peak}}$

$\Delta V_{outR} = I_{rect\_peak}\cdot ESR$

Where $I_{rect\_peak} = \dfrac{\pi}{2}\,I_o$

So:
$\Delta V_{outR} = \dfrac{\pi}{2}\,I_o\cdot ESR$

Capacitor RMS current $I_{C_o} = I_o \sqrt{\dfrac{\pi^2}{8} - 1}$

Total ripple — vector (RMS) sum with 90° phase shift $\Delta V_{out} = \sqrt{\Delta V_{outC}^2 + \Delta V_{outR}^2}$

$\Delta V_{out} = \sqrt{\left(\dfrac{I_o}{8\,f_{sw}\,C_o}\right)^2 + \left(I_{rect\_peak}\cdot ESR\right)^2}$

Replace $I_{rect\_peak}$:
$\Delta V_{out} = \sqrt{\left(\dfrac{I_o}{8\,f_{sw}\,C_o}\right)^2 + \left(\dfrac{\pi}{2}\,I_o\cdot ESR\right)^2}$

Solve for $C_o$ (RMS sum) $C_o \ge \dfrac{I_o}{8\,f_{sw}\,\sqrt{\Delta V_{out}^2 - \left(\dfrac{\pi}{2}\,I_o\cdot ESR\right)^2}}$
Condition: $\Delta V_{out} > \dfrac{\pi}{2}\,I_o\cdot ESR$

Solve for $ESR$ (RMS sum) $ESR \le \dfrac{1}{\dfrac{\pi}{2}\,I_o} \sqrt{\Delta V_{out}^2 - \left(\dfrac{I_o}{8\,f_{sw}\,C_o}\right)^2}$

Optional split of ripple budget (50%-50% rule) $\Delta V_{outR} < \dfrac{\Delta V_{out,max}}{2}$

$\Delta V_{outC} < \dfrac{\Delta V_{out,max}}{2}$

Implied bounds with 50/50 split:

$C_o \ge \dfrac{I_o}{8\,f_{sw}\,\left(\dfrac{\Delta V_{out,max}}{2}\right)} = \dfrac{I_o}{4\,f_{sw}\,\Delta V_{out,max}}$

$ESR \le \dfrac{\dfrac{\Delta V_{out,max}}{2}}{\dfrac{\pi}{2}\,I_o} = \dfrac{\Delta V_{out,max}}{\pi\,I_o}$

### Numerical Implementation of the Formulas 50% 50%¶

We must use fsw_min to the worst case

$ \begin{aligned} \mathrm{Io} &= 25.000 \; \;\textrm{(A)} \\[10pt] \mathrm{fsw}_{min} &= 60170.000 \; \;\textrm{(Hz)} \\[10pt] \mathrm{DV} &= 0.250 \; \;\textrm{(vpp)} \\[10pt] \mathrm{Co}_{min_{uF}} &= 1 \times 10 ^ {6} \cdot \frac{ \mathrm{Io} }{ 4 \cdot \mathrm{fsw}_{min} \cdot \mathrm{DV} } \\&= 1 \times 10 ^ {6} \cdot \frac{ 25.000 }{ 4 \cdot 60170.000 \cdot 0.250 } \\&= 415.489 \; \;\textrm{(uF)}\\[10pt] \end{aligned} $

$ \begin{aligned} \mathrm{ESR}_{max_{m}} &= 1 \times 10 ^ {3} \cdot \frac{ \mathrm{DV} }{ \mathrm{Io} \cdot \pi } \\&= 1 \times 10 ^ {3} \cdot \frac{ 0.250 }{ 25.000 \cdot 3.142 } \\&= 3.183 \; \;\textrm{(mΩ)}\\[10pt] \\[10pt] I_{Co} &= \mathrm{Io} \cdot \sqrt { \frac{ \left( \pi \right) ^{ 2 } }{ 8 } - 1 } \\&= 25.000 \cdot \sqrt { \frac{ \left( 3.142 \right) ^{ 2 } }{ 8 } - 1 } \\&= 12.086 \; \;\textrm{(Arms)}\\[10pt] \end{aligned} $

### First proposition¶

B40910A8127M000 aluminum electrolytic capacitors with Temp_max = 150°C, Below a screenshoot of the datasheet [2].

No description has been provided for this image

Figure 1: B40910A8127M000 aluminum electrolytic capacitors with Temp_max = 150°C

Let's start with a configuration of 6 capacitors in parallel, in the worst case ($C_{capa}= C_{min}$ of the datasheet)

$ \begin{aligned} \mathrm{Nb}_{capa} &= 6 \; \\[10pt] C_{capa_{nom}} &= 120 \; \;\textrm{(uF)} \\[10pt] \mathrm{Margin} &= 20 \; \;\textrm{(\%)} \\[10pt] C_{capa} &= C_{capa_{nom}} \cdot \left( 1 - \frac{ \mathrm{Margin} }{ 100 } \right) = 120 \cdot \left( 1 - \frac{ 20 }{ 100 } \right) &= 96.000 \; \;\textrm{(uF, Worst case)} \end{aligned} $

$ \begin{aligned} C_{eq} &= C_{capa} \cdot \mathrm{Nb}_{capa} = 96.000 \cdot 6 &= 576.000 \; \;\textrm{(uF > 415uF ok)} \\[10pt] \mathrm{ESR}_{capa} &= 17 \; \;\textrm{(Ω @ 100kHz)} \\[10pt] \mathrm{ESR}_{eq} &= \frac{ \mathrm{ESR}_{capa} }{ \mathrm{Nb}_{capa} } = \frac{ 17 }{ 6 } &= 2.833 \; \;\textrm{(Ω < 3.18m OK)} \\[10pt] \mathrm{Icapa}_{max} &= 4.600 \; \end{aligned} $

$ \begin{aligned} \mathrm{Ieq}_{max} &= \mathrm{Icapa}_{max} \cdot \mathrm{Nb}_{capa} \\&= 4.600 \cdot 6 \\&= 27.600 \; \;\textrm{(@ Arms @ 125°C 100kHz > 12.08Arms ok)}\\[10pt] \end{aligned} $

I_rect_peak

$ \begin{aligned} I_{rect_{peak}} &= \mathrm{Io} \cdot \frac{ \pi }{ 2 } = 25.000 \cdot \frac{ 3.142 }{ 2 } &= 39.270 \; \;\textrm{(A)} \end{aligned} $

Voltage ripples

$ \begin{aligned} \Delta_{V_{out}} &= \sqrt { \left( \frac{ \mathrm{Io} }{ 8 \cdot \mathrm{fsw}_{min} \cdot C_{eq} \cdot 1 \times 10 ^ {-6} } \right) ^{ 2 } + \left( \frac{ \pi }{ 2 } \cdot \mathrm{Io} \cdot \mathrm{ESR}_{eq} \cdot 1 \times 10 ^ {-3} \right) ^{ 2 } } \\&= \sqrt { \left( \frac{ 25.000 }{ 8 \cdot 60170.000 \cdot 576.000 \cdot 1 \times 10 ^ {-6} } \right) ^{ 2 } + \left( \frac{ 3.142 }{ 2 } \cdot 25.000 \cdot 2.833 \cdot 1 \times 10 ^ {-3} \right) ^{ 2 } } \\&= 0.143 \; \;\textrm{(V < 0.25V Ok)}\\[10pt] \end{aligned} $

#### Self heating¶

Power Dissipation of Each Capacitor

$ \begin{aligned} I_{each_{capa}} &= \frac{ I_{Co} }{ \mathrm{Nb}_{capa} } \\&= \frac{ 12.086 }{ 6 } \\&= 2.014 \; \;\textrm{(A)}\\[10pt] \\[10pt] P_{selfHeating} &= \mathrm{ESR}_{capa} \cdot 1 \times 10 ^ {-3} \cdot \left( I_{each_{capa}} \right) ^{ 2 } \\&= 17 \cdot 1 \times 10 ^ {-3} \cdot \left( 2.014 \right) ^{ 2 } \\&= 0.069 \; \;\textrm{(W)}\\[10pt] \end{aligned} $

Estimation of Thermal Resistance Rth

$ \begin{aligned} \Delta_{T} &= 150 - 125 &= 25 \; \;\textrm{(°C)} \\[10pt] \mathrm{ESR} &= 0.017 \; \\[10pt] I &= 4.600 \; \;\textrm{(Arms)} \\[10pt] P_{dissip} &= \mathrm{ESR} \cdot \left( I \right) ^{ 2 } \\&= 0.017 \cdot \left( 4.600 \right) ^{ 2 } \\&= 0.360 \; \;\textrm{(W)}\\[10pt] \\[10pt] R_{th} &= \frac{ \Delta_{T} }{ P_{dissip} } \\&= \frac{ 25 }{ 0.360 } \\&= 69.498 \; \;\textrm{(°C/W)}\\[10pt] \end{aligned} $

The self heating estimation and the max ambiant temp

$ \begin{aligned} \Delta_{T} &= P_{selfHeating} \cdot R_{th} \\&= 0.069 \cdot 69.498 \\&= 4.794 \; \;\textrm{(°C => low delta temp)}\\[10pt] \\[10pt] \mathrm{Margin} &= 30 \; \;\textrm{(°C)} \\[10pt] T_{max} &= 150 \; \\[10pt] T_{amb_{max}} &= T_{max} - \Delta_{T} - \mathrm{Margin} \\&= 150 - 4.794 - 30 \\&= 115.206 \; \;\textrm{(°C)}\\[10pt] \end{aligned} $

Voltage margin

$ \begin{aligned} \mathrm{Vo}_{max} &= 54.000 \; \;\textrm{(VDC)} \\[10pt] V_{max_{datasheet}} &= 63 \; \;\textrm{(VDC)} \\[10pt] \mathrm{Voltage}_{Margin} &= 100 \cdot \frac{ V_{max_{datasheet}} - \mathrm{Vo}_{max} }{ V_{max_{datasheet}} } \\&= 100 \cdot \frac{ 63 - 54.000 }{ 63 } \\&= 14.286 \; \;\textrm{(\%)}\\[10pt] \end{aligned} $

This solution is acceptable, but the voltage margin is limited.

### Second proposition¶

EMHS101ARA331MMN0S aluminum electrolytic capacitors with Temp_max = 150°C, Below a screenshoot of the datasheet [4].

No description has been provided for this image

Figure 2: EMHS101ARA331MMN0S aluminum electrolytic capacitors with Temp_max = 150°C

Let's start with a configuration of 10 capacitors in parallel, in the worst case ($C_{capa}= C_{min}$ of the datasheet)

$ \begin{aligned} \mathrm{Nb}_{capa} &= 10 \; \\[10pt] C_{capa_{nom}} &= 330 \; \;\textrm{(uF)} \\[10pt] \mathrm{Margin} &= 20 \; \;\textrm{(\%)} \\[10pt] C_{capa} &= C_{capa_{nom}} \cdot \left( 1 - \frac{ \mathrm{Margin} }{ 100 } \right) = 330 \cdot \left( 1 - \frac{ 20 }{ 100 } \right) &= 264.000 \; \;\textrm{(uF, Worst case)} \end{aligned} $

$ \begin{aligned} C_{eq} &= C_{capa} \cdot \mathrm{Nb}_{capa} = 264.000 \cdot 10 &= 2640.000 \; \;\textrm{(uF > 415uF ok)} \\[10pt] \mathrm{ESR}_{capa} &= 59 \; \;\textrm{(Ω @ 100kHz)} \\[10pt] \mathrm{ESR}_{eq} &= \frac{ \mathrm{ESR}_{capa} }{ \mathrm{Nb}_{capa} } = \frac{ 59 }{ 10 } &= 5.900 \; \;\textrm{(Ω > 3.18m NOK)} \end{aligned} $

Since the ESR does not satisfy the 50%–50% condition of the formula, we must use the full (unsimplified) expression for the voltage ripple.

$ \begin{aligned} \mathrm{Icapa}_{max} &= 2.300 \; \end{aligned} $

$ \begin{aligned} \mathrm{Ieq}_{max} &= \mathrm{Icapa}_{max} \cdot \mathrm{Nb}_{capa} \\&= 2.300 \cdot 10 \\&= 23.000 \; \;\textrm{(@ Arms @ 125°C 100kHz > 12.08Arms ok)}\\[10pt] \end{aligned} $

I_rect_peak

$ \begin{aligned} I_{rect_{peak}} &= \mathrm{Io} \cdot \frac{ \pi }{ 2 } = 25.000 \cdot \frac{ 3.142 }{ 2 } &= 39.270 \; \;\textrm{(A)} \end{aligned} $

Voltage ripples

$ \begin{aligned} \Delta_{V_{out}} &= \sqrt { \left( \frac{ \mathrm{Io} }{ 8 \cdot \mathrm{fsw}_{min} \cdot C_{eq} \cdot 1 \times 10 ^ {-6} } \right) ^{ 2 } + \left( \frac{ \pi }{ 2 } \cdot \mathrm{Io} \cdot \mathrm{ESR}_{eq} \cdot 1 \times 10 ^ {-3} \right) ^{ 2 } } \\&= \sqrt { \left( \frac{ 25.000 }{ 8 \cdot 60170.000 \cdot 2640.000 \cdot 1 \times 10 ^ {-6} } \right) ^{ 2 } + \left( \frac{ 3.142 }{ 2 } \cdot 25.000 \cdot 5.900 \cdot 1 \times 10 ^ {-3} \right) ^{ 2 } } \\&= 0.233 \; \;\textrm{(V < 0.25V Ok)}\\[10pt] \end{aligned} $

The condition is satisfied, but with a very limited margin.

#### Self heating¶

Power Dissipation of Each Capacitor

$ \begin{aligned} I_{each_{capa}} &= \frac{ I_{Co} }{ \mathrm{Nb}_{capa} } = \frac{ 12.086 }{ 10 } &= 1.209 \\[10pt] P_{selfHeating} &= \mathrm{ESR}_{capa} \cdot 1 \times 10 ^ {-3} \cdot \left( I_{each_{capa}} \right) ^{ 2 } \\&= 59 \cdot 1 \times 10 ^ {-3} \cdot \left( 1.209 \right) ^{ 2 } \\&= 0.086 \; \;\textrm{(W)}\\[10pt] \end{aligned} $

Estimation of Thermal Resistance Rth

$ \begin{aligned} \Delta_{T} &= 150 - 125 &= 25 \; \;\textrm{(°C)} \\[10pt] P_{dissip} &= \mathrm{ESR}_{capa} \cdot 1 \times 10 ^ {-3} \cdot \left( \mathrm{Icapa}_{max} \right) ^{ 2 } \\&= 59 \cdot 1 \times 10 ^ {-3} \cdot \left( 2.300 \right) ^{ 2 } \\&= 0.312 \; \;\textrm{(W)}\\[10pt] \\[10pt] R_{th} &= \frac{ \Delta_{T} }{ P_{dissip} } = \frac{ 25 }{ 0.312 } &= 80.100 \; \;\textrm{(°C/W)} \end{aligned} $

The self heating estimation and the max ambiant temp

$ \begin{aligned} \Delta_{T} &= P_{selfHeating} \cdot R_{th} = 0.086 \cdot 80.100 &= 6.903 \; \;\textrm{(°C => low delta temp)} \\[10pt] \mathrm{Margin} &= 30 \; \;\textrm{(°C)} \\[10pt] T_{max} &= 150 \; \\[10pt] T_{amb_{max}} &= T_{max} - \Delta_{T} - \mathrm{Margin} = 150 - 6.903 - 30 &= 113.097 \; \;\textrm{(°C)} \end{aligned} $

$ \begin{aligned} \mathrm{Vo}_{max} &= 54.000 \; \;\textrm{(VDC)} \\[10pt] V_{max_{datasheet}} &= 100 \; \;\textrm{(VDC)} \\[10pt] \mathrm{Voltage}_{Margin} &= 100 \cdot \frac{ V_{max_{datasheet}} - \mathrm{Vo}_{max} }{ V_{max_{datasheet}} } = 100 \cdot \frac{ 100 - 54.000 }{ 100 } &= 46.000 \; \;\textrm{(\%)} \end{aligned} $

### Comparaison¶

| requirements | Solutio1 | Solutio2
ESR_eq | 3.18 | 2.83 | 5.90
C_eq | 415.49 | 576.00 | 2640.00
Ieq_max | 12.09 | 27.60 | 23.00
VmaxDC | 54.00 | 63.00 | 100.00
Delta_V_out | 0.25 | 0.14 | 0.23
C_capa | NaN | 96.00 | 264.00
Nb_capa | NaN | 6.00 | 10.00
P_selfHeating | NaN | 0.07 | 0.09
T_amb_max | NaN | 115.21 | 113.10
Voltage_Margin | NaN | 14.29 | 46.00

*) The ESR requirement is based on the 50%–50% formula (see above for solution2).

The voltage margin in the first solution is limited (16% in the worst case). Nevertheless, I recommend proceeding with this option due to the number of parallel capacitors. Careful control is required to avoid overshoot or transient voltages, particularly when Vout is at its maximum.

## Input Capacitor Ci¶

We will use the same formula as the output capacitor above:

### Numerical Implementation of the Formulas 50% 50%¶

We must use fsw_min to the worst case

$ \begin{aligned} \mathrm{Ii} &= \frac{ \mathrm{Power} }{ V_{In_{min}} } = \frac{ 1200.000 }{ 360.000 } &= 3.333 \; \;\textrm{(A)} \\[10pt] \mathrm{fsw}_{min} &= 60170.000 \; \;\textrm{(Hz)} \\[10pt] \delta_{V} &= 1 \; \;\textrm{(\%)} \\[10pt] \mathrm{DV} &= V_{In_{nom}} \cdot \frac{ \delta_{V} }{ 100 } = 380.000 \cdot \frac{ 1 }{ 100 } &= 3.800 \; \;\textrm{(vpp)} \\[10pt] \mathrm{Ci}_{min_{uF}} &= 1 \times 10 ^ {6} \cdot \frac{ \mathrm{Ii} }{ 4 \cdot \mathrm{fsw}_{min} \cdot \mathrm{DV} } = 1 \times 10 ^ {6} \cdot \frac{ 3.333 }{ 4 \cdot 60170.000 \cdot 3.800 } &= 3.645 \; \;\textrm{(uF)} \end{aligned} $

$ \begin{aligned} \mathrm{ESR}_{max_{m}} &= 1 \times 10 ^ {3} \cdot \frac{ \mathrm{DV} }{ \mathrm{Ii} \cdot \pi } \\&= 1 \times 10 ^ {3} \cdot \frac{ 3.800 }{ 3.333 \cdot 3.142 } \\&= 362.873 \; \;\textrm{(mΩ)}\\[10pt] \\[10pt] I_{Ci} &= \mathrm{Ii} \cdot \sqrt { \frac{ \left( \pi \right) ^{ 2 } }{ 8 } - 1 } \\&= 3.333 \cdot \sqrt { \frac{ \left( 3.142 \right) ^{ 2 } }{ 8 } - 1 } \\&= 1.611 \; \;\textrm{(Arms)}\\[10pt] \end{aligned} $

### Film Capacitors MKP 1848e 4uF +/-5% 700V (MKP1848E54070JK2)¶

Let's start with this capacitor MKP1848E54070JK2 see the datasheet [5].

No description has been provided for this image

Figure 3: Mouser, Film Capacitors MKP 1848e 4uF +/-5% 700V (MKP1848E54070JK2)

No description has been provided for this image

Figure 4: Understund the part number

Signification of the part number

| MKP1848E54070JK2
MKP | METALLIZED POLYPROPYLENE
1848E | TYPE CONSTRUCTION
5 | MULTIPLIER (nF)=100
40 | CAPACITANCE 40=4000nF
70 | VOLTAGE UNDC = 70 = 700 VDC at 85 °C
J | TOLERANCE J=5%
K | Pitch code = K => P1=27.5mm
2 | 2 = 2pins

No description has been provided for this image

Figure 5: datasheet MKP1848E54070JK2, ESR= 12.5mOhom @10 kHz, Irms= 5.5A (Maximum RMS current at 10 kHz, +85 °C, Δt = +15 °C)

Verification

$ \begin{aligned} \mathrm{Tolerance} &= 5 \; \;\textrm{(\%)} \\[10pt] C_{Datasheet} &= 4 \; \;\textrm{(uF)} \\[10pt] \mathrm{Ci}_{min_{uF}} &= 3.645 \; \\[10pt] C_{Min} &= C_{Datasheet} \cdot \left( 1 - \frac{ \mathrm{Tolerance} }{ 100 } \right) = 4 \cdot \left( 1 - \frac{ 5 }{ 100 } \right) &= 3.800 \; \;\textrm{(uF > 3.645 uF)} \end{aligned} $

$ \begin{aligned} \mathrm{ESR}_{max_{m}} &= 362.873 \; \\[10pt] \mathrm{ESR}_{Datasheet} &= 12.500 \; \;\textrm{(mOhm < 362mOhm)} \end{aligned} $

$ \begin{aligned} \Delta_{V_{out}} &= \sqrt { \left( \frac{ \mathrm{Ii} }{ 8 \cdot \mathrm{fsw}_{min} \cdot C_{Min} \cdot 1 \times 10 ^ {-6} } \right) ^{ 2 } + \left( \frac{ \pi }{ 2 } \cdot \mathrm{Ii} \cdot \mathrm{ESR}_{Datasheet} \cdot 1 \times 10 ^ {-3} \right) ^{ 2 } } \\&= \sqrt { \left( \frac{ 3.333 }{ 8 \cdot 60170.000 \cdot 3.800 \cdot 1 \times 10 ^ {-6} } \right) ^{ 2 } + \left( \frac{ 3.142 }{ 2 } \cdot 3.333 \cdot 12.500 \cdot 1 \times 10 ^ {-3} \right) ^{ 2 } } \\&= 1.823 \; \;\textrm{(V)}\\[10pt] \\[10pt] \delta_{V_{out}} &= 100 \cdot \frac{ \Delta_{V_{out}} }{ V_{In_{nom}} } \\&= 100 \cdot \frac{ 1.823 }{ 380.000 } \\&= 0.480 \; \;\textrm{(\% < 1\% Ok)}\\[10pt] \end{aligned} $

Impedance curve

No description has been provided for this image

Figure 6: datasheet 700V 4uF, ESR ~ 12mOhm, Fres = 700kHz

Estimation of the ESL

$ \begin{aligned} C &= 4 \; \;\textrm{(uF)} \\[10pt] \mathrm{Fres} &= 700000.000 \; \;\textrm{(Hz)} \\[10pt] \mathrm{ESL} &= \frac{ 1 \times 10 ^ {9} }{ \left( 2 \cdot \pi \cdot \mathrm{Fres} \right) ^{ 2 } \cdot C \cdot 1 \times 10 ^ {-6} } = \frac{ 1 \times 10 ^ {9} }{ \left( 2 \cdot 3.142 \cdot 700000.000 \right) ^{ 2 } \cdot 4 \cdot 1 \times 10 ^ {-6} } &= 12.924 \; \;\textrm{(nH)} \end{aligned} $

Expectation life time

$ \begin{aligned} U_{OPDC} &= 400 \; \;\textrm{(Operation dc voltage)} \\[10pt] U_{NDC} &= 700 \; \;\textrm{(Nominal dc voltage)} \\[10pt] k &= \frac{ U_{OPDC} }{ U_{NDC} } = \frac{ 400 }{ 700 } &= 0.571 \end{aligned} $

No description has been provided for this image

Figure 7: Life time expectancy (h), k = 0.57, Tamb = 85°C ==> 200 000 h

$ \begin{aligned} \mathrm{Life}_{h} &= 200000 \; \;\textrm{(hours)} \\[10pt] \mathrm{Life}_{years} &= 22.831 \; \;\textrm{(Years)} \end{aligned} $

Tamb and current limit

No description has been provided for this image

Figure 8: For 105°C curve, and 85°C amb, no limite in the rms current, coef = 1

The self heating

From the datasheet

$ \begin{aligned} \mathrm{ESR} &= 12.500 \; \;\textrm{(mOhm)} \\[10pt] \mathrm{Icapa}_{rms} &= 5.500 \; \;\textrm{(Arms)} \\[10pt] \Delta_{T} &= 15 \; \;\textrm{(°C)} \end{aligned} $

Selg heating

$ \begin{aligned} \mathrm{Pd} &= \mathrm{ESR} \cdot 1 \times 10 ^ {-3} \cdot \left( \mathrm{Icapa}_{rms} \right) ^{ 2 } = 12.500 \cdot 1 \times 10 ^ {-3} \cdot \left( 5.500 \right) ^{ 2 } &= 0.378 \; \;\textrm{(W)} \\[10pt] \mathrm{Rth} &= \frac{ \Delta_{T} }{ \mathrm{Pd} } = \frac{ 15 }{ 0.378 } &= 39.669 \; \;\textrm{(°C/W)} \end{aligned} $

Maximum permissible ambient temperature in the application

$ \begin{aligned} I_{Ci} &= 1.611 \; \;\textrm{(the RMS current in our application)} \\[10pt] \mathrm{Pd} &= \left( I_{Ci} \right) ^{ 2 } \cdot \mathrm{ESR} \cdot 1 \times 10 ^ {-3} = \left( 1.611 \right) ^{ 2 } \cdot 12.500 \cdot 1 \times 10 ^ {-3} &= 0.032 \; \;\textrm{(W)} \\[10pt] \Delta_{T} &= \mathrm{Rth} \cdot \mathrm{Pd} = 39.669 \cdot 0.032 &= 1.288 \; \;\textrm{(°C)} \\[10pt] T_{capaMax} &= 105 \; \;\textrm{(°C)} \\[10pt] \mathrm{Margin} &= 10 \; \;\textrm{(°C)} \\[10pt] T_{ambMax} &= T_{capaMax} - \Delta_{T} - \mathrm{Margin} = 105 - 1.288 - 10 &= 93.712 \end{aligned} $

## Resonanat capacitor Cr¶

### Chosing a capacitor for Cr¶

The inputs data

$ \begin{aligned} \mathrm{Cr}_{nF} &= 116.209 \; \;\textrm{(nF)} \\[10pt] V_{In_{max}} &= 400.000 \; \;\textrm{(V)} \\[10pt] \mathrm{fsw}_{min} &= 60170.000 \; \;\textrm{(Hz)} \end{aligned} $

The RMS voltage of the resonant capacitor

$ \begin{aligned} X_{Cr} &= \frac{ 1 }{ 2 \cdot \pi \cdot \mathrm{fsw}_{min} \cdot \mathrm{Cr}_{nF} \cdot 1 \times 10 ^ {-9} } \\&= \frac{ 1 }{ 2 \cdot 3.142 \cdot 60170.000 \cdot 116.209 \cdot 1 \times 10 ^ {-9} } \\&= 22.761 \; \;\textrm{(Ohm)}\\[10pt] \end{aligned} $

$ \begin{aligned} V_{Cr} &= \mathrm{Ir}_{rms} \cdot X_{Cr} = 10.354 \cdot 22.761 &= 235.672 \; \;\textrm{(V)} \\[10pt] V_{Cr_{rms}} &= \sqrt { \left( \frac{ V_{In_{max}} }{ 2 } \right) ^{ 2 } + \left( V_{Cr} \right) ^{ 2 } } = \sqrt { \left( \frac{ 400.000 }{ 2 } \right) ^{ 2 } + \left( 235.672 \right) ^{ 2 } } &= 309.098 \; \;\textrm{(vrms)} \end{aligned} $

Starting with the B3267*L film capacitors, the maximum rated DC voltage is 2000 V. [2].

The design value of Cr is 116.2 nF
Below are some possible combinations for constructing this resonant capacitor:

| Nominal_capa_nF | Nb capas in parallel | total capa nF | error %
0 | 6.2 | 19 | 117.8 | 1.4
1 | 6.8 | 17 | 115.6 | -0.5
2 | 8.2 | 14 | 114.8 | -1.2
3 | 10.0 | 12 | 120.0 | 3.3
4 | 12.0 | 10 | 120.0 | 3.3
5 | 15.0 | 8 | 120.0 | 3.3
6 | 22.0 | 5 | 110.0 | -5.3
7 | 33.0 | 4 | 132.0 | 13.6
8 | 47.0 | 2 | 94.0 | -19.1
9 | 56.0 | 2 | 112.0 | -3.6
10 | 68.0 | 2 | 136.0 | 17.0

The current of each element capacitor

$ \begin{aligned} \mathrm{Ir}_{rms_{1}} &= 1.294 \; \end{aligned} $

The 15 nF, 15 mm, 2000 VDC TDK MKP capacitor meets both the Vrms and Irms requirements.

No description has been provided for this image

Figure 9: Vrms 15 nF, 15 mm, 2000 VDC TDK MKP

No description has been provided for this image

Figure 10: Irms 15 nF, 15 mm, 2000 VDC TDK MKP

Below is a screenshot from the B32672L datasheet. The ref B32672L8153 is a 15 nF capacitor.

No description has been provided for this image

Figure 11: B32672L8153 is a 15 nF capacitor.

The ESR and Power dissipation

No description has been provided for this image

Figure 12: ESR and Thermal derating

From the below
6.8nF ESR=70µΩ
33nF ESR=50µΩ
By linear interpolation, the ESR of a 15 nF capacitor can be estimated as 63.74 µΩ

The power dissipation of each capacitor

$ \begin{aligned} \mathrm{ESR}_{u} &= 63.740 \; \;\textrm{(µΩ)} \\[10pt] \mathrm{Ir}_{rms_{1}} &= 1.294 \; \;\textrm{(Arms)} \\[10pt] \mathrm{Ir}_{rms_{max}} &= 2 \; \;\textrm{(Arms)} \\[10pt] \mathrm{PD}_{uW} &= \mathrm{ESR}_{u} \cdot \left( \mathrm{Ir}_{rms_{1}} \right) ^{ 2 } = 63.740 \cdot \left( 1.294 \right) ^{ 2 } &= 106.771 \; \;\textrm{(uW)} \end{aligned} $

The Rth estimation

$ \begin{aligned} T_{max} &= 125 \; \\[10pt] T_{100} &= 100 \; \\[10pt] \Delta_{T} &= T_{max} - T_{100} = 125 - 100 &= 25 \\[10pt] \mathrm{PD}_{uW_{max}} &= \mathrm{ESR}_{u} \cdot \left( \mathrm{Ir}_{rms_{max}} \right) ^{ 2 } = 63.740 \cdot \left( 2 \right) ^{ 2 } &= 254.962 \\[10pt] R_{TH} &= \frac{ \Delta_{T} }{ \mathrm{PD}_{uW_{max}} } = \frac{ 25 }{ 254.962 } &= 0.098 \; \;\textrm{(°C/uW)} \end{aligned} $

Each capacitor's self-heating and the maximum permissible ambient temperature.

$ \begin{aligned} \Delta_{T} &= \mathrm{PD}_{uW} \cdot R_{TH} = 106.771 \cdot 0.098 &= 10.469 \; \;\textrm{(°C)} \\[10pt] T_{amb_{max}} &= 125 - \Delta_{T} = 125 - 10.469 &= 114.531 \; \;\textrm{(°C)} \end{aligned} $

### Understanding the Derating Curve of the Capacitors¶

One point calculation

$ \begin{aligned} \mathrm{Ta} &= 105 \; \\[10pt] \Delta_{T} &= T_{max} - \mathrm{Ta} = 125 - 105 &= 20 \\[10pt] \mathrm{PD}_{uW_{max}} &= \frac{ \Delta_{T} }{ R_{TH} } = \frac{ 20 }{ 0.098 } &= 203.969 \\[10pt] \mathrm{Ir}_{rms_{max_{Ta}}} &= 1.789 \; \\[10pt] \mathrm{Fa} &= \frac{ \mathrm{Ir}_{rms_{max_{Ta}}} }{ \mathrm{Ir}_{rms_{max}} } = \frac{ 1.789 }{ 2 } &= 0.894 \end{aligned} $

The same calculation is repeated to construct the derating curve.

(80.0, 125.0)

No description has been provided for this image

### Resonant capacitors configuration¶

There are two possible configurations for the resonant capacitors:

- All capacitors in parallel:

which is the classic LLC configuration and offers simplicity in layout.

- Dividing the capacitors between the high side and low side:

which helps balance HV+ and HV-.

Below is a simulation of both solutions. We can see that the voltage and current of each capacitor are almost identical in both configurations, and all other voltages and currents are also very similar.

You can donwload the LTSPICE file using this Link.

No description has been provided for this image

Figure 13: Simulation of resonant capacitor configurations

## Bill of Materials (BOM) of this part¶

| Mouser No | Mfr. No | Number | componenent | remark
0 | 871-B40910A8127M000 | B40910A8127M000 | 6 | Output capa | Alum capa - SMD 63VDC 120uF (M) d10x125 mm SMD HP
1 | 75-MKP1848E54070JK2 | MKP1848E54070JK2 | 1 | Input capa | Film Capacitors MKP 1848e 4uF +/-5% 700V
2 | 871-B32672L8153J | B32672L8153J | 8 | Resonant capa | Film Cap 15NF 5% 700VAC MKP BOXED

## References¶

[1] Hong Huang, Designing an LLC Resonant Half-Bridge Power Converter. Available: https://bbs.dianyuan.com/upload/community/2013/12/01/1385867010-65563.pdf

[2] B40910 Aluminum electrolytic capacitors datasheet (https://product.tdk.com/system/files/dam/doc/product/capacitor/aluminum-electrolytic/hybrid-polymer/data_sheet/20/30/db/aec/b40910.pdf)

[3] B3267*L Film Capacitors (https://product.tdk.com/system/files/dam/doc/product/capacitor/film/mkp_mfp/data_sheet/20/20/db/fc_2009/mkp_b32671l_672l.pdf)

[4] EMHS Aluminum electrolytic capacitors datasheet (https://www.mouser.fr/datasheet/2/420/Chemi_Con_MHSRA_e-3313675.pdf)

[5] Film Capacitors MKP 1848e 4uF +/-5% 700V datasheet , MKP1848E54070JK2 (https://www.vishay.com/docs/26085/mkp1848edclink.pdf)

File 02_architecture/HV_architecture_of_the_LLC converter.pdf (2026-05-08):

# Main HV architecture of the LLC converter

1200W 400V/48V LLC DC-DC Converter Design (https://github.com/BOAB235/Design_of_1200W_LLC_DCDC) - Main HV architecture of the LLC converter


Abdelaziz BOUZIANI 2026-04-03 | 1

# Table of contents

Primary mosfet
Resonant capacitor
Secondary mosfets
Ground connection
The main full topology of the LLC DC‑DC Auxiliary power supplies
Primary and secondary drivers Architecture of sensors
HW protection
Communication

# Primary mosfet

For this LLC DC–DC converter, we can choose between a full‑bridge or a half‑bridge configuration on the primary side. Here is a comparison of the two approaches:

Feature | Half Bridge LLC | Full Bridge LLC
Number of switches | 2 | 4
Voltage applied to resonant tank | Vin/2 | Vin
Power capability(*) | Medium | High
Transformer turns ratio | Higher | Lower
Conduction losses(*) | Higher (more current) | Lower
Cost | Lower | Higher
Control complexity | Simpler | Slightly more complex

(*) : In a half‑bridge topology, the applied voltage is half that of a full bridge, so delivering the same power requires roughly twice the current. This higher current increases copper losses, which in turn restricts the maximum power capability.


Figure 1: Primary mosfet configuration: Left: Full bridge, Right: Half bridge

We will select the half‑bridge topology because it offers lower cost and simpler control. This choice is fully compatible with our 1.2 kW power target.

# Resonant capacitor

For the half‑bridge configuration, we have two options: using one bloc of resonant capacitor or dividing it into two separate blocs of capacitors (see the illustration below).


Figure 2: LLC tank configuration: Left: One resonant capacitor, Right: Splited resonant capacitor

Below is a comparison of the two configurations.

Both designs use identical values for Lm, Lr, and C, and the same total number of capacitors. The only distinction is that:

In the first simulation, the capacitors are split into two blocks, with one connected to HV+ and the other to HV-.
In the second simulation, all capacitors are combined into a single block connected to HV-.


Figure 3: LLC tank configuration: Left: One resonant capacitor, Right: Splited resonant capacitor

From a power-electronics standpoint, the two configurations behave very similarly.
This is evident when comparing their small-signal models:

the capacitor voltage (green curve) and the current (red curve) show almost identical waveforms in both implementations.

Therefore, we will choose the simpler approach: grouping all the capacitors into a single block, primarily to optimize the PCB layout and reduce area usage.

But for EMI constraints, we must keep in mind that the symmetric solution, which consists of splitting the capacitors into two blocks, is better, and the chosen solution creates an asymmetric path that can worsen EMI disturbances.

# Secondary mosfets

We can choose between using diodes or MOSFETs in the secondary stage.

At 1.2 kW and 48 V output, the output current is around 25 A.
Depending on the configuration, but if we assume this same current flows continuously through a MOSFET with a voltage drop of 0.2 V and through a diode with a drop of 0.8 V, the losses would be 5 W in the MOSFET and 20 W in the diode.

Diodes are still used as secondary rectifiers in some modern 11 kW EV chargers, but the key difference is the output voltage. At around 400 V output, a 0.2 V MOSFET drop or a 1.2 V diode drop has minimal impact on efficiency. However, at low‑voltage, high‑current outputs such as 12 V, this voltage drop becomes significant, making MOSFETs the better choice.

In conclusion, rectifier diodes are low‑cost, require no control, and simplify the layout, but they offer the poorest efficiency and create major challenges in thermal management.

For this reason, we will use MOSFETs in the output stage.

However, we still have three possible secondary‑side configurations, as shown in the figure below:

A full‑bridge rectifier
A half‑bridge with a center‑tapped transformer and MOSFETs, where the winding is pulled down to ground
A half‑bridge with a center‑tapped transformer and MOSFETs, where the winding is pulled up to the positive rail (V+)


Figure 4: Secondary mosfet configuration: (a): Full bridge, (b): Half bridge & source to ground, (c): Half bridge & drain to ground

Below a comparaison of those tree solutions:

Feature | Full-Bridge Rectifier | Center-Tapped (Pull- Down MOSFETs)

Center-Tapped (Pull-Up
MOSFETs)
Secondary topology | Single secondary winding with 4 rectifiers (diodes or MOSFETs) | Center-tapped secondary with 2 MOSFETs pulling to GND | Center-tapped secondary with 2 MOSFETs pulling to V+
Number of rectifiers | 4 devices | 2 devices | 2 devices
Transformer requirement | Single secondary winding | Center-tapped secondary winding | Center-tapped secondary winding
Transformer copper usage | Better utilization | Slightly worse (two half windings) | Slightly worse (two half windings)
Current in secondary winding | Current flows through full winding | Current flows through half winding at a time | Current flows through half winding at a time
Voltage stress on rectifiers | Lower | Higher | Higher
Conduction path | Two devices conduct each cycle | One MOSFET conducts each half-cycle | One MOSFET conducts each half-cycle
Conduction losses | Higher (two drops in series) | Lower | Lower
RMS current per device | Lower per device | Higher per device | Higher per device

Feature | Full-Bridge Rectifier | Center-Tapped (Pull- Down MOSFETs)

Center-Tapped (Pull-Up
MOSFETs)
Gate drive complexity (MOSFET SR) | Higher (4 devices to control) | Lower (ref to ground) | Lower (but require insulation)
PCB layout complexity | Higher | Moderate | More Simple
Efficiency at low output voltage | Lower | Higher | Higher

For these reasons, we will select the middle option, where the MOSFET source is connected to V– (ground).
This configuration allows the gate driver to be ground‑referenced, making it fully compatible with our existing power‑supply architecture, as detailed in below in this document.

# Ground connection

For safety reasons, the primary side will be isolated, but for the output side we have two possible options:

Keep the output floating (isolated) Reference the output to the system ground (OUT‑ connected to ground) For example, in Tesla’s 400 V/48 V DC‑DC converters, OUT‑ is grounded.

Below is a comparison table of these two solutions:

Feature | Floating Output (Isolated) | Grounded Output (OUT- tied to GND)
Isolation level | Full galvanic isolation maintained | Output referenced to ground
Safety | Higher protection from ground faults | Depends on system grounding scheme
Common-mode noise | Usually higher | Lower EMI and better noise control
Measurement simplicity | Harder (no reference) | Easier (clear ground reference)
System integration | Flexible for different loads | Simpler integration with grounded systems
Fault behavior | Floating nodes may drift | Fault currents have defined return path
EMI performance | Worse common-mode emissions | Often improved EMI behavior
PCB layout | More complexe | Simple output zone

We will adopt the grounded output to simplify the PCB layout and improve EMI performance.

# The main full topology of the LLC DC‑DC

Below is the main topology of this LLC DC‑DC, including all the points discussed above.


Figure 5: The final architecture of the 1200W LLC DCDC converter

# Auxiliary power supplies

We selected the following topology for the auxiliary power supplies:

Primary zone

Flyback: A flyback converter generates 12V from the 400V input. Its secondary ground is tied to HV-, and all primary‑side grounds are intended to be connected to HV- (HVN). The 12V output also supplies the low‑side driver, while the high‑side driver uses a bootstrap circuit.
A non‑isolated buck converter steps the 12V from the flyback down to 3.3V to power the MCU and all primary‑side signal components.

Secondary zone

A non‑isolated buck converter steps the 48V main secondary voltage down to 12V to power the synchronous secondary drivers.
An LDO then converts the 12V to 3.3V for the isolated voltage amplifier on the secondary side.


Figure 6: The topology for the auxiliary power supplies

# Primary and secondary drivers

The primary‑side driver circuit is configured as follows:

Low‑side VDDA is powered directly from the flyback's 12V output.
High‑side VDDB is supplied by a bootstrap network that includes a current‑limiting resistor in series with a high‑voltage fast‑recovery diode.


Figure 7: The primary side driver circuitry

As the secondary MOSFET sources are referenced to the secondary ground, the secondary synchronous drivers are supplied directly by the 12V output of the buck converter.

# Architecture of sensors

The figure below show the architecture of the main seonsors:

Current senosrs

Input current: Isolated hall current sensor to measure the input current, powered by the 3.3v primary auxilary power supplay, and referensed to the HVN.
Output current: Isolated hall current sensor to measure the output current, powered by the 3.3v primary auxilary power supplay, and referensed to the HVN.

Voltage sensors

Input voltage: Since the MUC is refereced to the HVN, this sensor is a simple voltage diveder between HVP and HVN.
Output voltage: A voltage divider flowed by an isolated amplifier.

Temperature sensors

Two CTN are used to meaure the PCB temperatures; one close to the primary mosfet region, the second is closed to the secondary mofset region. Each CTN is a low side thermal resistor in serial with a pull up precision resistor, and in parallel with a decoupling capacitor.

The figure below shows the architecture of the main sensors:

Current sensors

Input current: An isolated Hall current sensor is used to measure the input current. It is powered by the 3.3 V primary auxiliary power supply and referenced to the HVN.
Output current: An isolated Hall current sensor is used to measure the output current. It is powered by the 3.3 V primary auxiliary power supply and referenced to the HVN.

Voltage sensors

Input voltage: As the MCU is referenced to the HVN, this measurement is implemented using a simple voltage divider between HVP and HVN.
Output voltage: A voltage divider followed by an isolated amplifier is used.

Temperature sensors

Two CTNs are used to measure PCB temperatures: one located near the primary MOSFET region and the other near the secondary MOSFET region. Each CTN is configured as a low-side thermal resistor in series with a precision pull-up resistor and in parallel with a decoupling capacitor.


Figure 8: The architecture of the main sensors

The STM32F1 MCU also offers the possibility to measure the CPU temperature, so this temperature will be used as a second-range sensor.

# HW protection

For safety reasons, a hardware protection circuit will be used.

The HW protection is composed of four fast open-drain comparators.
The outputs are connected to a common node with a pull-up resistor.
The comparator outputs are used to clear a D flip-flop, while the preset is controlled by the MCU. The D flip-flop is used to disable the primary driver.
The four comparators are triggered by input/output voltage and input/output current sensor signals.
The comparator reference voltages are generated using four simple potentiometers. Therefore, the HW protection functions include input/output OCP (over current protection) and input/output OVP (over voltage protection).


Figure 9: The HW protection circuit: Primary/Secondary OVP/OVP

# Communication

Since the MCU is referenced to HVN, and for safety reasons, we will use an HV-isolated SPI interface.

This circuit will be powered by 3.3 V on the MCU side, and by an external 3.3 V supply on the isolated output side.
From the external point of view, the DC-DC will provide 6 communication pins: 4 for SPI and 2 to power the isolated interface.
The DC-DC MCU will operate as an SPI slave, while the external management circuit will be the SPI master.
Communication will be detailed in the SW design. In general, the DC-DC must report measurements such as input/output voltage and current, and receive output targets such as voltage, current, and power. If communication is not established, the DC-DC must apply default settings: 48 V output voltage and 1200 W maximum power (outside temperature derating).


Figure 10: HV insulation circuit for SPI communication

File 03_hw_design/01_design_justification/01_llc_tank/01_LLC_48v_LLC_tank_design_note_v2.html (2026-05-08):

# LLC tank pre-design calculations¶

No description has been provided for this image

## Table of contents¶

  - Voltage Gain – Theoretical Overview
  - Inputs and Specifications
  - Transfo ratio and Voltage Gain
  - Lm, Lr, Cr tank
  - Simulations
  - References

### Voltage Gain – Theoretical Overview¶

No description has been provided for this image

Figure 1: The simplified schematic and the equivalent small-signal AC model

The voltage gain function (normalized) expression is:

$$ M_g = \left| \frac{L_n \cdot f_n^2}{\left[(L_n + 1) \cdot f_n^2 - 1\right] + j\left[(f_n^2 - 1) \cdot f_n \cdot Q_e \cdot L_n\right]} \right| $$

With:

$$ L_n = \frac{L_m}{L_r}, \quad Q_e = \frac{\sqrt{\frac{L_r}{C_r}}}{R_e}, \quad f_n = \frac{f_{sw}}{f_0}, \quad f_0 = \frac{1}{2\pi\sqrt{L_r C_r}} $$ See page 3 formula (23) [1].
You can found all formula of this chapeter in the same ref

No description has been provided for this image

### Inputs and Specifications¶

$ \begin{aligned} V_{In_{min}} &= 360 \; \;\textrm{(v)} \\[10pt] V_{In_{nom}} &= 380 \; \;\textrm{(v)} \\[10pt] V_{In_{max}} &= 400 \; \;\textrm{(v)} \end{aligned} $

$ \begin{aligned} \mathrm{Vo}_{min} &= 42 \; \;\textrm{(v)} \\[10pt] \mathrm{Vo}_{nom} &= 48 \; \;\textrm{(v)} \\[10pt] \mathrm{Vo}_{max} &= 54 \; \;\textrm{(v)} \end{aligned} $

$ \begin{aligned} \mathrm{Power} &= 1200 \; \;\textrm{(w)} \\[10pt] f_{nom} &= 100000.000 \; \;\textrm{(Hz)} \end{aligned} $

Inputs data

{'V_In_min': 360.0,
 'V_In_nom': 380.0,
 'V_In_max': 400.0,
 'Vo_min': 42.0,
 'Vo_nom': 48.0,
 'Vo_max': 54.0,
 'Power': 1200.0,
 'f_nom': 100000.0}

### Transfo ratio and Voltage Gain¶

$ \begin{aligned} n &= \frac{ V_{In_{nom}} }{ \mathrm{Vo}_{nom} \cdot 2 } = \frac{ 380 }{ 48 \cdot 2 } &= 3.958 \end{aligned} $

Choose an integer value to simplify the transformer design.

$ \begin{aligned} n &= \operatorname{round} \left( n \right) = \operatorname{round} \left( 4 \right) &= 4 \end{aligned} $

$ \begin{aligned} \mathrm{Vf} &= 0.200 \; \;\textrm{(drop voltage in the mos)} \\[10pt] \mathrm{efficiency} &= 0.950 \; \;\textrm{(hypothesis)} \\[10pt] \mathrm{loss} &= 1 - \mathrm{efficiency} = 1 - 0.950 &= 0.050 \\[10pt] \mathrm{Io}_{nom} &= \frac{ \mathrm{Power} }{ \mathrm{Vo}_{nom} } = \frac{ 1200 }{ 48 } &= 25.000 \; \;\textrm{(A)} \\[10pt] V_{loss} &= \frac{ \frac{ \mathrm{Power} \cdot \mathrm{loss} }{ \mathrm{efficiency} } }{ \mathrm{Io}_{nom} } = \frac{ \frac{ 1200 \cdot 0.050 }{ 0.950 } }{ 25.000 } &= 2.526 \; \;\textrm{(v)} \end{aligned} $

$ \begin{aligned} \mathrm{margin} &= 0.010 \; \\[10pt] \mathrm{Mg}_{min} &= n \cdot \frac{ \mathrm{Vo}_{min} \cdot \left( 1 - \mathrm{margin} \right) + \mathrm{Vf} }{ \frac{ V_{In_{max}} }{ 2 } } \\&= 4 \cdot \frac{ 42 \cdot \left( 1 - 0.010 \right) + 0.200 }{ \frac{ 400 }{ 2 } } \\&= 0.836 \\[10pt] \end{aligned} $

$ \begin{aligned} \mathrm{Mg}_{max} &= n \cdot \frac{ \mathrm{Vo}_{max} \cdot \left( 1 + \mathrm{margin} \right) + \mathrm{Vf} + V_{loss} }{ \frac{ V_{In_{min}} }{ 2 } } \\&= 4 \cdot \frac{ 54 \cdot \left( 1 + 0.010 \right) + 0.200 + 2.526 }{ \frac{ 360 }{ 2 } } \\&= 1.273 \\[10pt] \\[10pt] \mathrm{Mg}_{max110} &= \mathrm{Mg}_{max} \cdot \left( \frac{ 110 }{ 100 } \right) \\&= 1.273 \cdot \left( \frac{ 110 }{ 100 } \right) \\&= 1.400 \\[10pt] \end{aligned} $

### Lm, Lr, Cr tank¶

Below we will use grid search to find the best values for Ln and Qe.

The idea:

- Change Ln in the range: start = 1, stop = 10, step = 0.01 (around 100 points)
- Change Qe in the range: start = 0.1, stop = 1, step = 0.01 (around 10 points)

We will select the Ln and Qe values that give an Mg value closest to Mg_max110.

Top 6 (Ln, Qe) Combinations Matching Mg_max110
The following 6 values of Ln and Qe closely match the target voltage gain Mg_max110.
These rows were selected based on the criterion that Mg_ape is nearly equal to Mg_max110.

$ \begin{aligned} \mathrm{Mg}_{max110} &= 1.400 \; \end{aligned} $

| Lnc | Qec | Lm_uH | Lr_uH | Cr_nF | fn_min | fn_max | fsw_min | fsw_max | Mg_ape
0 | 2.41 | 0.64 | 61.127 | 25.364 | 99.867314 | 0.6375 | 1.3790 | 63750.0 | 137900.0 | 1.400142
1 | 3.00 | 0.55 | 65.392 | 21.797 | 116.209238 | 0.6017 | 1.5622 | 60170.0 | 156220.0 | 1.400062
2 | 3.46 | 0.50 | 68.562 | 19.816 | 127.830162 | 0.5707 | 1.7698 | 57070.0 | 176980.0 | 1.399923
3 | 3.68 | 0.48 | 70.005 | 19.023 | 133.156419 | 0.5471 | 1.9035 | 54710.0 | 190350.0 | 1.400284
4 | 4.21 | 0.44 | 73.413 | 17.438 | 145.261548 | 0.5324 | 2.4133 | 53240.0 | 241330.0 | 1.400277
5 | 4.71 | 0.41 | 76.532 | 16.249 | 155.890441 | 0.5077 | 3.6928 | 50770.0 | 369280.0 | 1.400231

No description has been provided for this image

$ \begin{aligned} \mathrm{Lnc} &= 3 \; \\[10pt] \mathrm{Qec} &= 0.550 \; \end{aligned} $

Lnc = 3 and Qec = 0.55 represent an optimal compromise due to the following:

- Moderate gain slope (ΔM/Δf): In the inductive region, the gain rises gradually with frequency, enabling stable control without abrupt sensitivity shifts.
- Limited frequency span (f_min to f_max): These parameters restrict the switching frequency range, simplifying component design, controller implementation, and consistent ZVS operation.

No description has been provided for this image

## ¶

#### Equivalent resistor¶

$ \begin{aligned} \mathrm{Re}_{nom} &= 8 \cdot \left( n \right) ^{ 2 } \cdot \frac{ \mathrm{Vo}_{nom} }{ \left( \pi \right) ^{ 2 } \cdot \mathrm{Io}_{nom} } \\&= 8 \cdot \left( 4 \right) ^{ 2 } \cdot \frac{ 48 }{ \left( 3.142 \right) ^{ 2 } \cdot 25.000 } \\&= 24.901 \\[10pt] \\[10pt] \mathrm{Re}_{nom} &= \operatorname{round} \left( \mathrm{Re}_{nom} ,\ 3 \right) \\&= \operatorname{round} \left( 24.901 ,\ 3 \right) \\&= 24.901 \\[10pt] \\[10pt] \mathrm{Re}_{110} &= 8 \cdot \left( n \right) ^{ 2 } \cdot \frac{ \mathrm{Vo}_{nom} }{ \left( \pi \right) ^{ 2 } \cdot \mathrm{Io}_{nom} \cdot 1.1 } \\&= 8 \cdot \left( 4 \right) ^{ 2 } \cdot \frac{ 48 }{ \left( 3.142 \right) ^{ 2 } \cdot 25.000 \cdot 1.1 } \\&= 22.637 \\[10pt] \\[10pt] P_{re_{110}} &= \frac{ \left( \frac{ V_{In_{nom}} }{ 2 } \right) ^{ 2 } }{ \mathrm{Re}_{nom} } \\&= \frac{ \left( \frac{ 380 }{ 2 } \right) ^{ 2 } }{ 24.901 } \\&= 1449.741 \\[10pt] \end{aligned} $

#### Lm, Lr, Cr values¶

$ \begin{aligned} \mathrm{Cr}_{nF} &= \frac{ 1 \times 10 ^ {9} }{ 2 \cdot \pi \cdot \mathrm{Qec} \cdot f_{nom} \cdot \mathrm{Re}_{nom} } \\&= \frac{ 1 \times 10 ^ {9} }{ 2 \cdot 3.142 \cdot 0.550 \cdot 100000.000 \cdot 24.901 } \\&= 116.209 \; \;\textrm{(nF)}\\[10pt] \end{aligned} $

$ \begin{aligned} \mathrm{Cr} &= 116.209 \; \\[10pt] \mathrm{Cr} &= \operatorname{round} \left( \mathrm{Cr} ,\ 3 \right) \\&= \operatorname{round} \left( 116.209 ,\ 3 \right) \\&= 116.209 \\[10pt] \end{aligned} $

$ \begin{aligned} \mathrm{Lr} &= \frac{ 1 }{ \left( 2 \cdot \pi \cdot f_{nom} \right) ^{ 2 } \cdot \mathrm{Cr} \cdot 1 \times 10 ^ {-9} } \\&= \frac{ 1 }{ \left( 2 \cdot 3.142 \cdot 100000.000 \right) ^{ 2 } \cdot 116.209 \cdot 1 \times 10 ^ {-9} } \\&= 0.000 \\[10pt] \\[10pt] \mathrm{Lr}_{uH} &= \mathrm{Lr} \cdot 1 \times 10 ^ {6} \\&= 0.000 \cdot 1 \times 10 ^ {6} \\&= 21.797 \; \;\textrm{(uH)}\\[10pt] \\[10pt] \mathrm{Lr}_{uH} &= \operatorname{round} \left( \mathrm{Lr}_{uH} ,\ 3 \right) \\&= \operatorname{round} \left( 21.797 ,\ 3 \right) \\&= 21.797 \\[10pt] \end{aligned} $

$ \begin{aligned} \mathrm{Lm} &= \mathrm{Lr} \cdot \mathrm{Lnc} \\&= 0.000 \cdot 3.000 \\&= 0.000 \\[10pt] \\[10pt] \mathrm{Lm}_{uH} &= \mathrm{Lm} \cdot 1 \times 10 ^ {6} \\&= 0.000 \cdot 1 \times 10 ^ {6} \\&= 65.392 \; \;\textrm{(uH)}\\[10pt] \end{aligned} $

$ \begin{aligned} L_{second_{uH}} &= \frac{ \mathrm{Lm}_{uH} }{ \left( n \right) ^{ 2 } } \\&= \frac{ 65.392 }{ \left( 4 \right) ^{ 2 } } \\&= 4.087 \; \;\textrm{(uH)}\\[10pt] \end{aligned} $

Verification

$ \begin{aligned} \mathrm{Qcal} &= \frac{ \sqrt { \frac{ \mathrm{Lr} }{ \mathrm{Cr} \cdot 1 \times 10 ^ {-9} } } }{ \mathrm{Re}_{110} \cdot 1.1 } = \frac{ \sqrt { \frac{ 0.000 }{ 116.209 \cdot 1 \times 10 ^ {-9} } } }{ 22.637 \cdot 1.1 } &= 0.550 \\[10pt] \mathrm{Qec} &= 0.550 \; \end{aligned} $

#### Fsw limites and primary secondary currents¶

$ \begin{aligned} \mathrm{fsw}_{min} &= \mathrm{fn}_{min} \cdot f_{nom} \\&= 0.602 \cdot 100000.000 \\&= 60170.000 \; \;\textrm{(Hz)}\\[10pt] \\[10pt] \mathrm{fsw}_{max} &= \mathrm{fn}_{max} \cdot f_{nom} \\&= 1.562 \cdot 100000.000 \\&= 156220.000 \; \;\textrm{(Hz)}\\[10pt] \\[10pt] \mathrm{wmin} &= 2 \cdot \pi \cdot \mathrm{fsw}_{min} \\&= 2 \cdot 3.142 \cdot 60170.000 \\&= 378059.260 \; \;\textrm{(rad/s)}\\[10pt] \\[10pt] \mathrm{wmax} &= 2 \cdot \pi \cdot \mathrm{fsw}_{max} \\&= 2 \cdot 3.142 \cdot 156220.000 \\&= 981559.209 \; \;\textrm{(rad/s)}\\[10pt] \end{aligned} $

$ \begin{aligned} \mathrm{Im}_{rms} &= 2 \cdot \sqrt { 2 } \cdot n \cdot \frac{ \mathrm{Vo}_{nom} }{ \pi \cdot \mathrm{Lm} \cdot \mathrm{wmin} } \\&= 2 \cdot \sqrt { 2 } \cdot 4 \cdot \frac{ 48 }{ 3.142 \cdot 0.000 \cdot 378059.260 } \\&= 6.992 \; \;\textrm{(Arms)}\\[10pt] \end{aligned} $

$ \begin{aligned} \mathrm{Io} &= 25.000 \; \;\textrm{(Arms)} \\[10pt] \mathrm{Ioe}_{rms} &= 1.1 \cdot \pi \cdot \frac{ \mathrm{Io} }{ n \cdot 2 \cdot \sqrt { 2 } } \\&= 1.1 \cdot 3.142 \cdot \frac{ 25.000 }{ 4 \cdot 2 \cdot \sqrt { 2 } } \\&= 7.636 \; \;\textrm{(Arms @ 110%)}\\[10pt] \\[10pt] \mathrm{Ios}_{rms} &= \mathrm{Ioe}_{rms} \cdot n \\&= 7.636 \cdot 4 \\&= 30.545 \; \;\textrm{(Arms)}\\[10pt] \end{aligned} $

$ \begin{aligned} \mathrm{Ir}_{rms} &= \sqrt { \left( \mathrm{Im}_{rms} \right) ^{ 2 } + \left( \mathrm{Ioe} \right) ^{ 2 } } \\&= \sqrt { \left( 6.992 \right) ^{ 2 } + \left( 7.636 \right) ^{ 2 } } \\&= 10.354 \; \;\textrm{(Arms)}\\[10pt] \end{aligned} $

Output data

{'Lnc': 3.0,
 'Qec': 0.55,
 'Cr_nF': 116.209,
 'n': 4.0,
 'Lr_uH': 21.797,
 'Lm_uH': 65.392,
 'fsw_min': 60170.0,
 'fsw_max': 156220.0,
 'Im_rms': 6.992,
 'Io': 25.0,
 'Ioe_rms': 7.636,
 'Ios_rms': 30.545,
 'Ir_rms': 10.354,
 'L_second_uH': 4.087,
 'Re_nom': 24.901,
 'Re_110': 22.637,
 'Cr': 1.16209e-07,
 'Lr': 2.1796999999999998e-05,
 'Lm': 6.539199999999999e-05}

### Simulations¶

AC simulation of the LLC gain

No description has been provided for this image

Figure 2: AC response of the LLC tank, for load is 10, 20, 40, 60, 80 and 100% of Re_110

The frequency response is close to our calculated target for frequencies in the range [F_min, F_max].

you can donwload the simulation file here

Simple simulation (nominal)

No description has been provided for this image

Figure 3: The simulation of the LLC tank

The output is around 48V for an input of 380V and 100kHz (nominal).
The Lm current is close to a sine wave form as expected (resonanance).

you can donwload the simulation file here (https://github.com/BOAB235/Design_of_1200W_LLC_DCDC/tree/main/03_hw_design/01_design_justification/01_llc_tank/02_simulation/04_simple_model)

### References¶

[1] Hong Huang, Designing an LLC Resonant Half-Bridge Power Converter. Available: https://bbs.dianyuan.com/upload/community/2013/12/01/1385867010-65563.pdf [2]
Code Python notebook used to make this PDF (https://github.com/BOAB235/Design_of_1200W_LLC_DCDC/blob/main/03_hw_design/01_design_justification/01_llc_tank/01_LLC_48v_LLC_tank_design_note_v2.ipynb)

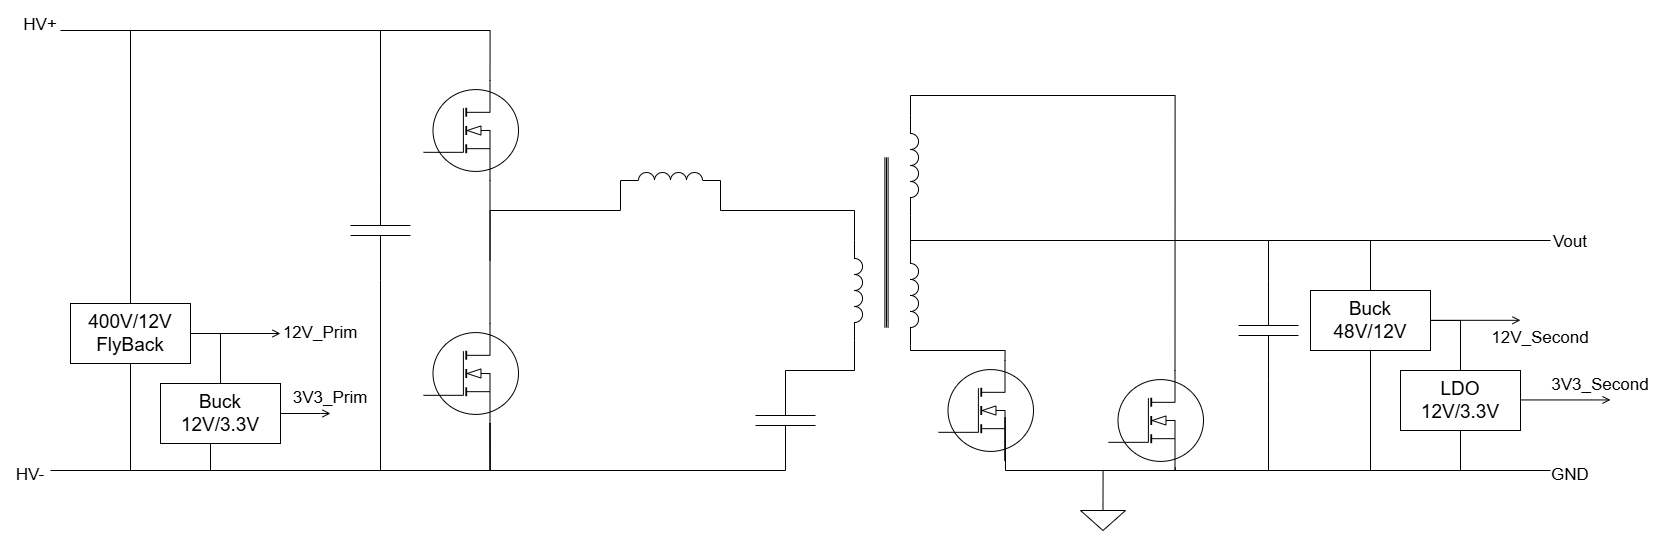
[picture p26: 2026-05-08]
02_architecture/figs/Power_supp2.png

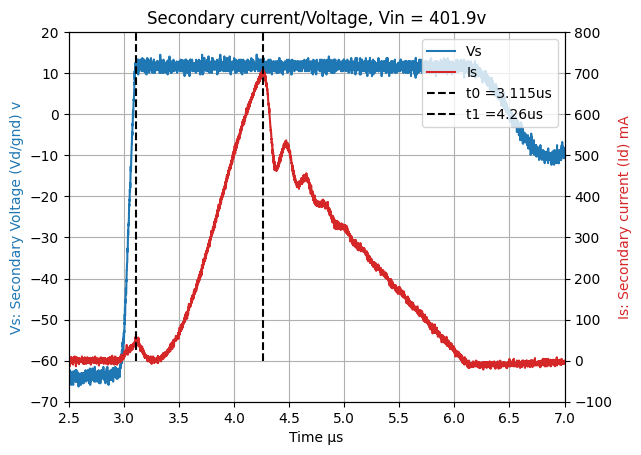
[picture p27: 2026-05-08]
03_hw_design/01_design_justification/07_power_supp/01_FlyBack/figs/Tny264_zoom_Is2.png

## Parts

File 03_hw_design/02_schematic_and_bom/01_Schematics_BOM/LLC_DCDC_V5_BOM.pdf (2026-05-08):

Market | Mouser No: | Mfr. No: | Desc.: | Customer No | Order Qty. | Price (EUR) Sub Total (Euro) Order Date:
Mouser | 871-B66297KX197 | B66297K0000X197 | Ferrite Cores & Accessories Ferrite Cores & Accessories I102/7/37.5 N97 9600 + 25- 25% | | 1 | 11.21 € | 11.21 € | 05-Sep-25
Mouser | 871-B66297GX197 | B66297G0000X197 | Ferrite Cores & Accessories Ferrite Cores & Accessories ELP102/20.3/37.5 N97 8500 + 25- 25% | | 1 | 12.22 € | 12.22 € | 05-Sep-25
Mouser | 512-FDH055N15A | FDH055N15A | MOSFETs MOSFETs 150V N-Channel PowerTrench MOSFET | | 2 | 5.65 € | 11.30 € | 05-Sep-25
Mouser | 871-B40910A8127M000 | B40910A8127M000 | Aluminium Electrolytic Capacitors - SMD Aluminium Electrolytic Capacitors - SMD 63VDC 120uF (M) d10x125 mm SMD HP | | 6 | 2.29 € | 13.74 € | 05-Sep-25
Mouser | 871-B32672L8153J | B32672L8153J | Film Capacitors Film Capacitors Film Cap 15NF 5% 700VAC MKP BOXED | | 10 | 0.35 € | 3.45 € | 05-Sep-25
Mouser | 726-IPW60R037CM8XKSA | IPW60R037CM8XKSA1 | MOSFETs MOSFETs HIGH POWER_NEW | | 2 | 6.11 € | 12.22 € | 05-Sep-25
Mouser | 187-CL31A106KBHNNNE | CL31A106KBHNNNE | Multilayer Ceramic Capacitors MLCC - SMD/SMT Multilayer Ceramic Capacitors MLCC - SMD/SMT 10uF+/-10% 50V X5R 3 1206 | | 2 | 0.10 € | 0.19 € | 26-Sep-25
Mouser | 791-SH21B104K101CT | SH21B104K101CT | Multilayer Ceramic Capacitors MLCC - SMD/SMT Multilayer Ceramic Capacitors MLCC - SMD/SMT 100V 0.1 uF 10% X7R - 55 C + 125 C 0805 Flex Term | | 22 | 0.04 € | 0.81 € | 26-Sep-25
Mouser | 871-B81123C1222M | B81123C1222M | Safety Capacitors Safety Capacitors 0.0022uF 500Vac 20% Class Y1 | | 5 | 0.61 € | 3.06 € | 26-Sep-25
Mouser | 81-GRM31CR71E106KA2K | GRM31CR71E106KA12K | Multilayer Ceramic Capacitors MLCC - SMD/SMT Multilayer Ceramic Capacitors MLCC - SMD/SMT 10 uF 25 VDC 10% 1206 X7R | | 18 | 0.12 € | 2.07 € | 26-Sep-25
Mouser | 80-A768EB107M1ELAS36 | A768EB107M1ELAS036 | Aluminium Organic Polymer Capacitors Aluminium Organic Polymer Capacitors 25Vol 100uF SMD 2KHr ESR=36 mOhms AECQ200 | | 1 | 0.46 € | 0.46 € | 26-Sep-25
Mouser | 603-AC1206JKNPOZB103 | AC1206JKNPOZBN103 | Multilayer Ceramic Capacitors MLCC - SMD/SMT Multilayer Ceramic Capacitors MLCC - SMD/SMT 630V 10nF NPO 5% 1206 AEC-Q200 | | 1 | 0.51 € | 0.51 € | 26-Sep-25
Mouser | 80-C0805C102J5G | C0805C102J5GACTU | Multilayer Ceramic Capacitors MLCC - SMD/SMT Multilayer Ceramic Capacitors MLCC - SMD/SMT 50V 1000pF C0G 0805 5% | | 25 | 0.06 € | 1.58 € | 26-Sep-25
Mouser | 80-R46KI310050M1K | R46KI310050M1K | Safety Capacitors Safety Capacitors 275vac 0.1uF 10% | | 2 | 0.30 € | 0.60 € | 26-Sep-25
Mouser | 667-EEV-FK1V471Q | EEV-FK1V471Q | Aluminium Electrolytic Capacitors - SMD Aluminium Electrolytic Capacitors - SMD 470uF 35V | | 3 | 1.27 € | 3.81 € | 26-Sep-25
Mouser | 710-875115350002 | 875115350002 | Aluminium Organic Polymer Capacitors Aluminium Organic Polymer Capacitors WCAP-PSHP 16V 220uF 20% ESR=20mOhms | | 1 | 1.22 € | 1.22 € | 26-Sep-25
Mouser | 504-EFDKS60K405D032L | EFDKS60K405D032LH | Film Capacitors Film Capacitors CAP FILM 4uF 10% 600VDC RAD | | 1 | 1.61 € | 1.61 € | 26-Sep-25
Mouser | 871-B40910A8127M000 | B40910A8127M000 | Aluminium Electrolytic Capacitors - SMD Aluminium Electrolytic Capacitors - SMD 63VDC 120uF (M) d10x125 mm SMD HP | | 1 | 2.29 € | 2.29 € | 26-Sep-25
Mouser | 673-PA2750NL | PA2750NL | Common Mode Chokes / Filters Common Mode Chokes / Filters 9.4mOhms 400uH 6A SMD Toroid Choke | | 1 | 1.87 € | 1.87 € | 26-Sep-25
Mouser | 637-US1J | US1J | Rectifiers Rectifiers Ultrafast, SMA, 600V, 1A, 150C | | 1 | 0.25 € | 0.25 € | 26-Sep-25
Mouser | 863-MBRS340T3G | MBRS340T3G | Schottky Diodes & Rectifiers Schottky Diodes & Rectifiers 3A 40V | | 5 | 0.65 € | 3.23 € | 26-Sep-25
Mouser | 863-NCP43080DDR2G | NCP43080DDR2G | Switching Controllers Switching Controllers SECONDARY SIDE SYNCHRONOU | | 2 | 0.47 € | 0.95 € | 26-Sep-25
Mouser | 998-LM2575-3.3WUTR | LM2575-3.3WU-TR | Switching Voltage Regulators Switching Voltage Regulators 1A Step-Down SMPS Regulator | | 1 | 1.51 € | 1.51 € | 26-Sep-25
Mouser | 926-LM2575HVS12NOPB | LM2575HVS-12/NOPB | Switching Voltage Regulators Switching Voltage Regulators 1A SD Vtg Reg | | 1 | 4.16 € | 4.16 € | 26-Sep-25
Mouser | 873-SI8932B-IS | SI8932B-IS | Isolation Amplifiers Isolation Amplifiers | | 1 | 5.17 € | 5.17 € | 26-Sep-25
Mouser | 595-SN74HC74DRG4 | SN74HC74DRG4 | Flip-Flops Flip-Flops Dual Pos-Edge-Trig D -Type Flip-Flop ALT 595-SN74HC74DR | | 1 | 0.48 € | 0.48 € | 26-Sep-25
Mouser | 595-TMCS1107A1UQDRQ1 TMCS1107A1UQDRQ1 | | Board Mount Current Sensors Board Mount Current Sensors AEC-Q100 +/-420-V i solated Hall-effect | | 1 | 3.41 € | 3.41 € | 26-Sep-25
Mouser | 250-70331EOLCTR005U3 | ACS70331EOLCTR-005U3 | Board Mount Current Sensors Board Mount Current Sensors For New Designs Use ACS730 or ACS71240LLC | | 1 | 1.91 € | 1.91 € | 26-Sep-25
Mouser | 595-ISO7741BDWR | ISO7741BDWR | Digital Isolators Digital Isolators Robust EMC quad-cha nnel 3/1 reinforce A 595-ISO7741BDW | | 1 | 2.35 € | 2.35 € | 26-Sep-25
Mouser | 634-SI82390BD-IS | SI82390BD-IS | Galvanically Isolated Gate Drivers Galvanically Isolated Gate Drivers 5 kV 8 V UVLO dual isolated gate driver | | 1 | 5.07 € | 5.07 € | 26-Sep-25
Mouser | 621-AZ1117CH2-33TRG1 | AZ1117CH2-3.3TRG1 | LDO Voltage Regulators LDO Voltage Regulators BJT Low Dropout Regulator SOT223 T&R 4K | | 1 | 0.19 € | 0.19 € | 26-Sep-25
Mouser | 542-PM5022-331M-RC | PM5022-331M-RC | Power Inductors - SMD Power Inductors - SMD 330uH 20% | | 2 | 0.59 € | 1.17 € | 26-Sep-25
Mouser | 869-TNY280GN-TL | TNY280GN-TL | AC/DC Converters AC/DC Converters 28.5W 85-265 VAC 36.5W/230 VAC | | 1 | 1.46 € | 1.46 € | 26-Sep-25
Mouser | 621-DPC817S-B-TR | DPC817S-B-TR | Transistor Output Optocouplers Transistor Output Optocouplers Photo Coupler SL-4 T&R 2K | | 1 | 0.31 € | 0.31 € | 26-Sep-25
Mouser | 726-BCP5616H6327X | BCP5616H6327XTSA1 | Bipolar Transistors - BJT Bipolar Transistors - BJT AF TRANSISTORS | | 1 | 0.65 € | 0.65 € | 26-Sep-25
Mouser | 755-KTR18EZPJ3R0 | KTR18EZPJ3R0 | Thick Film Resistors - SMD Thick Film Resistors - SMD 1206 3ohm 5% High VoltageAEC-Q200 | | 10 | 0.08 € | 0.75 € | 26-Sep-25
Mouser | 603-RC1206FR-0711K5L | RC1206FR-0711K5L | Thick Film Resistors - SMD Thick Film Resistors - SMD General Purpose Chip Resistor 1206, 11.5kOhms, 1%, 1/4W | | 20 | 0.01 € | 0.18 € | 26-Sep-25
Mouser | 708-RNCE1206BTE10R0 | RNCE1206BTE10R0 | Thin Film Resistors - SMD Thin Film Resistors - SMD 10Ohms 1206 25ppm 1/4W 200V 0.1% Hi Temp/Stability | | 2 | 0.27 € | 0.53 € | 26-Sep-25
Mouser | 571-9-2176070-5 | 9-2176070-5 | Thick Film Resistors - SMD Thick Film Resistors - SMD 3521 82K 1% 2W | | 2 | 0.25 € | 0.50 € | 26-Sep-25
Mouser | 603-RT1206BRD0756KL | RT1206BRD0756KL | Thin Film Resistors - SMD Thin Film Resistors - SMD 1/4W 56K ohm .1% 25p pm | | 10 | 0.10 € | 0.99 € | 26-Sep-25
Mouser | 71-CRCW12060000Z0EAC | CRCW12060000Z0EAC | Thick Film Resistors - SMD Thick Film Resistors - SMD 1/4Watt 0ohms Commercial Use | | 10 | 0.02 € | 0.22 € | 26-Sep-25
Mouser | 755-SFR10EZPF2200 | SFR10EZPF2200 | Thick Film Resistors - SMD Thick Film Resistors - SMD Sulfur Tolerant Chip Resistor, 2012mm, +/-1%, 150V, 0.125W, 220 ohm | | 10 | 0.05 € | 0.47 € | 26-Sep-25
Mouser | 652-CR1206FX-1071ELF | CR1206-FX-1071ELF | Thick Film Resistors - SMD Thick Film Resistors - SMD 1.07K 1% | | 10 | 0.02 € | 0.24 € | 26-Sep-25
Mouser | 71-M251206BB5108JP50 | M251206BB5108JP500 | Thin Film Resistors - SMD Thin Film Resistors - SMD 5.1 OHM 5% 100PPM 1/4W | | 2 | 0.29 € | 0.58 € | 26-Sep-25
Mouser | 708-RNCE1206BTE1K00 | RNCE1206BTE1K00 | Thin Film Resistors - SMD Thin Film Resistors - SMD 1KOhms 1206 25ppm 1/4W 200V 0.1% Hi Temp/Stability | | 1 | 0.27 € | 0.27 € | 26-Sep-25
Mouser | 667-ERA-8AEB152V | ERA-8AEB152V | Thin Film Resistors - SMD Thin Film Resistors - SMD 1206 1.5Kohm 0.1% 25ppm | | 1 | 0.18 € | 0.18 € | 26-Sep-25
Mouser | 660-RN73R2BTD4991B25 | RN73R2BTTD4991B25 | Thin Film Resistors - SMD Thin Film Resistors - SMD 4990 ohm 0.1% 0.25W | | 2 | 0.23 € | 0.46 € | 26-Sep-25
Mouser | 603-RC1206JR-071R1L | RC1206JR-071R1L | Thick Film Resistors - SMD Thick Film Resistors - SMD General Purpose Chip Resistor 1206, 1.1Ohms, 5%, 1/4W | | 10 | 0.02 € | 0.20 € | 26-Sep-25
Mouser | 755-LTR100JZPJ270 | LTR100JZPJ270 | Current Sense Resistors - SMD Current Sense Resistors - SMD High-Power/Wide-Terminal/Anti-Surge Chip Resistor, 3264mm, 3W, 200V, +/-0.5%, 27 ohm | | 1 | 0.52 € | 0.52 € | 26-Sep-25
Mouser | 756-LRMAP2512R007FT4 | LRMAP2512-R007FT4 | Current Sense Resistors - SMD Current Sense Resistors - SMD 3W 0.007 Ohm 1% | | 1 | 0.28 € | 0.28 € | 26-Sep-25
Mouser | 588-TX08F103F3435ER | TX08F103F3435ER | NTC (Negative Temperature Coefficient) Thermistors NTC (Negative Temperature Coefficient) Thermistors THERMISTOR 0805 10K/3435 | | 2 | 0.10 € | 0.19 € | 26-Sep-25
Mouser | 595-TLV9024QDRQ1 | TLV9024QDRQ1 | Analog Comparators Analog Comparators Automotive 5.5-V l ow-voltage high-per | | 1 | 1.81 € | 1.81 € | 26-Sep-25
Mouser | 621-BZT52C11-F | BZT52C11-7-F | Zener Diodes Zener Diodes 500mW 11V Zener | | 1 | 0.10 € | 0.10 € | 26-Sep-25
Mouser | 871-B66461G0000X187 | B66461G0000X187 | Ferrite Cores & Accessories Ferrite Cores & Accessories ELP43/10/28 N87OL NO RECESS | | 2 | 2.61 € | 5.22 € | 26-Sep-25
Mouser | 871-B66285G0000X187 | B66285G0000X187 | Ferrite Cores & Accessories Ferrite Cores & Accessories ELP22/6/16 N87OL | | 1 | 1.10 € | 1.10 € | 26-Sep-25
Mouser | 871-B66285KX187 | B66285K0000X187 | Ferrite Cores & Accessories Ferrite Cores & Accessories I22/2.5/16 N87 5200 +25% -25% | | 1 | 1.69 € | 1.69 € | 26-Sep-25
Aliexpress | NA | 3296W-1-203RLF | Trimmer Resistors - Through Hole 3/8" 20Kohms Sealed Vertical Adjust 25 turns 10% 2.54mm | | 4 | | 1.35 € | 10/12/2025
Aliexpress | NA | LM4040AIM3-2.0 | Voltage References PREC MICROPWR SHUNT VLTG REF SOT23 2.048V ±2mV and ±15mV | | 1 | | 1.90 € | 10/12/2025
Aliexpress | NA | | heatsink 300*140*20mm / 11.81*5.51*0.78" Weight 570g, 19 fins Material: Aluminum | | 1 | 11.29 € | 11.29 € | 10/12/2025
Aliexpress | NA | | 2.54mm Double Row Female 10P Breakaway PCB Board Pin Header Socket Connector Pinheader | | 2 | | 1.13 € | 10/12/2025
Aliexpress | NA | | Hex Brass Male Female Motherboard Standoff Mount M2.5 Thread 6mm Board Rack Stud Threaded Pillar PCB Column Spacer Screw | | 11 | | 3.19 € | 10/12/2025
Aliexpress | NA | | Hexagon Hex Nuts M2.5 Hex Nut 304 Stainless Steel DIN934 Metric | | 15 | | 1.14 € | 10/12/2025
Aliexpress | NA | JD102MY5VY1 | 400VAC 102M 1NF | | 4 | | 1.91 € | 10/12/2025
Aliexpress | NA | | M2.5 long gb818 a2 304 stainless steel cross round phillips pan head screw bolt length=12mm | | 15 | | 1.20 € | 10/12/2025
JLCPCB | NA | | PCB FR-4 1.6mm 4 layers inner 35um (1oz) outer 70um (2oz), 140mmx300mm | | 1 | | 107.02 € | 10/12/2025
# | Confidential C

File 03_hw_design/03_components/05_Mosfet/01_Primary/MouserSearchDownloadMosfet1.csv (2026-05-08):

Mouser Part Number | Mfr Part Number | Mfr. | Datasheet | Availability | Pricing | RoHS | Lifecycle | Product Detail | Technology | Mounting Style | Package/Case | Transistor Polarity | Number of Channels | Vds - Drain-Source Breakdown Voltage | Id - Continuous Drain Current | Rds On - Drain-Source Resistance | Vgs - Gate-Source Voltage | Vgs th - Gate-Source Threshold Voltage | Qg - Gate Charge | Minimum Operating Temperature | Maximum Operating Temperature | Pd - Power Dissipation | Channel Mode | Qualification | Tradename | Packaging
726-IPW60R099P7XKSA1 | IPW60R099P7XKSA1 | Infineon Technologies | https://www.mouser.fr/datasheet/2/196/Infineon_IPW60R099P7_DS_v02_01_EN-3362773.pdf | 1 347 In Stock | ="3,67 €" | RoHS Compliant |  | https://www.mouser.fr/ProductDetail/Infineon-Technologies/IPW60R099P7XKSA1?qs=HXFqYaX1Q2xJyB3sLTuhug%3D%3D | Si | Through Hole | TO-247-3 | N-Channel | 1 Channel | 600 V | ="31 A" | 77 mOhms | - 20 V, + 20 V | 3 V | 45 nC | - 55 C | + 150 C | 117 W | Enhancement |  | CoolMOS | Tube
726-IPZA60R080P7XKSA | IPZA60R080P7XKSA1 | Infineon Technologies | https://www.mouser.fr/datasheet/2/196/Infineon_IPZA60R080P7_DS_v02_01_EN-3362673.pdf | 174 In Stock | ="4,03 €" | RoHS Compliant |  | https://www.mouser.fr/ProductDetail/Infineon-Technologies/IPZA60R080P7XKSA1?qs=xhbEVWpZdWdjgvPQ0o6Epg%3D%3D | Si | Through Hole | TO-247-4 | N-Channel | 1 Channel | 600 V | ="37 A" | 69 mOhms | - 20 V, + 20 V | 3 V | 51 nC | - 55 C | + 150 C | 129 W | Enhancement |  | CoolMOS | Tube
726-IPZA60R099P7XKSA | IPZA60R099P7XKSA1 | Infineon Technologies | https://www.mouser.fr/datasheet/2/196/Infineon_IPZA60R099P7_DS_v02_01_EN-3362753.pdf | 310 In Stock | ="4,19 €" | RoHS Compliant |  | https://www.mouser.fr/ProductDetail/Infineon-Technologies/IPZA60R099P7XKSA1?qs=xhbEVWpZdWeLTomzsCKMLg%3D%3D | Si | Through Hole | TO-247-4 | N-Channel | 1 Channel | 600 V | ="31 A" | 77 mOhms | - 20 V, + 20 V | 3 V | 45 nC | - 55 C | + 150 C | 117 W | Enhancement |  | CoolMOS | Tube
511-STW65N60DM6 | STW65N60DM6 | STMicroelectronics | https://www.st.com/resource/en/datasheet/stw65n60dm6.pdf | 587 In Stock | ="4,59 €" | RoHS Compliant By Exemption |  | https://www.mouser.fr/ProductDetail/STMicroelectronics/STW65N60DM6?qs=byeeYqUIh0OjmTd2UOzyxg%3D%3D | Si | Through Hole | TO-247-3 | N-Channel | 1 Channel | 600 V | ="38 A" | 71 mOhms | - 25 V, + 25 V | 3.25 V | 54 nC | - 55 C | + 150 C | 250 W | Enhancement |  | MDmesh | Tube
511-STW48N60DM2 | STW48N60DM2 | STMicroelectronics | https://www.st.com/resource/en/datasheet/stw48n60dm2.pdf | 477 In Stock | ="4,73 €" | RoHS Compliant By Exemption |  | https://www.mouser.fr/ProductDetail/STMicroelectronics/STW48N60DM2?qs=mKNKSX85ZJe00J5n%2Fw3nAg%3D%3D | Si | Through Hole | TO-247-3 | N-Channel | 1 Channel | 600 V | ="40 A" | 65 mOhms | - 25 V, + 25 V | 3 V | 70 nC | - 55 C | + 150 C | 300 W | Enhancement |  | MDmesh | Tube
511-STW45N65M5 | STW45N65M5 | STMicroelectronics | https://www.st.com/resource/en/datasheet/stw45n65m5.pdf | 703 In Stock | ="4,73 €" | RoHS Compliant By Exemption |  | https://www.mouser.fr/ProductDetail/STMicroelectronics/STW45N65M5?qs=vK53sQ86l6d3C3tot9T2Iw%3D%3D | Si | Through Hole | TO-247-3 | N-Channel | 1 Channel | 650 V | ="35 A" | 78 mOhms | - 25 V, + 25 V | 3 V | 82 nC | - 55 C | + 150 C | 210 W | Enhancement |  | MDmesh | Tube
833-MCW075N60FH-BP | MCW075N60FH-BP | Micro Commercial Components (MCC) | https://www.mouser.fr/datasheet/2/258/MCW075N60FH_TO_247_-3536278.pdf | 360 In Stock | ="4,85 €" |  | New Product | https://www.mouser.fr/ProductDetail/Micro-Commercial-Components-MCC/MCW075N60FH-BP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 | Si | Through Hole | TO-247-3 | N-Channel | 1 Channel | 600 V | ="41 A" | 75 mOhms | - 30 V, + 30 V | 5 V | 81 nC | - 55 C | + 150 C | 312.5 W | Enhancement |  |  | Bulk
726-IPW60R060C7XKSA1 | IPW60R060C7XKSA1 | Infineon Technologies | https://www.mouser.fr/datasheet/2/196/Infineon_IPW60R060C7_DS_v02_00_EN-1731945.pdf | 410 In Stock | ="4,94 €" | RoHS Compliant |  | https://www.mouser.fr/ProductDetail/Infineon-Technologies/IPW60R060C7XKSA1?qs=QIiuLP2W41BeappdMvA3rg%3D%3D | Si | Through Hole | TO-247-3 | N-Channel | 1 Channel | 600 V | ="35 A" | 52 mOhms | - 20 V, + 20 V | 3 V | 68 nC | - 55 C | + 150 C | 162 W | Enhancement |  | CoolMOS | Tube
726-IPW60R080P7XKSA1 | IPW60R080P7XKSA1 | Infineon Technologies | https://www.mouser.fr/datasheet/2/196/Infineon_IPW60R080P7_DS_v02_01_EN-3362671.pdf | 2 778 In Stock | ="4,96 €" | RoHS Compliant |  | https://www.mouser.fr/ProductDetail/Infineon-Technologies/IPW60R080P7XKSA1?qs=HXFqYaX1Q2zfvdpDHxlTLg%3D%3D | Si | Through Hole | TO-247-3 | N-Channel | 1 Channel | 600 V | ="37 A" | 69 mOhms | - 20 V, + 20 V | 3 V | 51 nC | - 55 C | + 150 C | 129 W | Enhancement |  | CoolMOS | Tube
511-STW48N60M2 | STW48N60M2 | STMicroelectronics | https://www.st.com/resource/en/datasheet/stw48n60m2.pdf | 987 In Stock | ="5,04 €" | RoHS Compliant By Exemption |  | https://www.mouser.fr/ProductDetail/STMicroelectronics/STW48N60M2?qs=Ok1pvOkw6%2Fos4i0EI03Hxw%3D%3D | Si | Through Hole | TO-247-3 | N-Channel | 1 Channel | 600 V | ="42 A" | 70 mOhms | - 25 V, + 25 V | 2 V | 70 nC | - 55 C | + 150 C | 300 W | Enhancement |  | MDmesh | Tube
512-FCH067N65S3_F155 | FCH067N65S3-F155 | onsemi / Fairchild | https://www.onsemi.com/PowerSolutions/product.do?id=FCH067N65S3-F155 | 872 In Stock | ="5,09 €" | RoHS Compliant |  | https://www.mouser.fr/ProductDetail/onsemi-Fairchild/FCH067N65S3-F155?qs=0lQeLiL1qyblDbVpX%2FdZeg%3D%3D | Si | Through Hole | TO-247-3 | N-Channel | 1 Channel | 650 V | ="44 A" | 67 mOhms | - 30 V, + 30 V | 2.5 V | 78 nC | - 55 C | + 150 C | 312 W | Enhancement |  | SuperFET III | Tube
863-NVHL072N65S3 | NVHL072N65S3 | onsemi | https://www.onsemi.com/PowerSolutions/product.do?id=NVHL072N65S3 | 343 In Stock | ="5,16 €" | RoHS Compliant By Exemption |  | https://www.mouser.fr/ProductDetail/onsemi/NVHL072N65S3?qs=l7cgNqFNU1gCEmusphpJ0Q%3D%3D | Si | Through Hole | TO-247-3 | N-Channel | 1 Channel | 650 V | ="44 A" | 72 mOhms | - 30 V, + 30 V | 2.5 V | 82 nC | - 55 C | + 150 C | 312 W | Enhancement | AEC-Q101 | SuperFET III | Tube
511-STWA48N60DM2 | STWA48N60DM2 | STMicroelectronics | https://www.st.com/resource/en/datasheet/stwa48n60dm2.pdf | 560 In Stock | ="5,27 €" | RoHS Compliant By Exemption |  | https://www.mouser.fr/ProductDetail/STMicroelectronics/STWA48N60DM2?qs=u4fy%2FsgLU9OBNCcRV2yziA%3D%3D | Si | Through Hole | TO-247-3 | N-Channel | 1 Channel | 600 V | ="40 A" | 65 mOhms | - 25 V, + 25 V | 3 V | 70 nC | - 55 C | + 150 C | 300 W | Enhancement |  | MDmesh | Tube
863-NVHL050N65S3HF | NVHL050N65S3HF | onsemi | https://www.onsemi.com/PowerSolutions/product.do?id=NVHL050N65S3HF | 564 In Stock | ="5,30 €" | RoHS Compliant By Exemption |  | https://www.mouser.fr/ProductDetail/onsemi/NVHL050N65S3HF?qs=W%2FMpXkg%252BdQ6QGz%2FCfzP%252BDw%3D%3D | Si | Through Hole | TO-247-3 | N-Channel | 1 Channel | 650 V | ="58 A" | 50 mOhms | - 30 V, + 30 V | 5 V | 119 nC | - 55 C | + 150 C | 403 W | Enhancement | AEC-Q101 |  | Tube
511-STW70N60M2 | STW70N60M2 | STMicroelectronics | https://www.st.com/resource/en/datasheet/stw70n60m2.pdf | 802 In Stock | ="5,38 €" | RoHS Compliant By Exemption |  | https://www.mouser.fr/ProductDetail/STMicroelectronics/STW70N60M2?qs=Rlwi1sSxVL4hmaII3E%2FvIA%3D%3D | Si | Through Hole | TO-247-3 | N-Channel | 1 Channel | 600 V | ="68 A" | 30 mOhms | - 25 V, + 25 V | 3 V | 118 nC | - 55 C | + 150 C | 450 W | Enhancement |  | MDmesh | Tube
78-SIHG065N60E-GE3 | SIHG065N60E-GE3 | Vishay Semiconductors | https://www.vishay.com/doc?92036 | 2 080 In Stock | ="5,41 €" | RoHS Compliant |  | https://www.mouser.fr/ProductDetail/Vishay-Semiconductors/SIHG065N60E-GE3?qs=byeeYqUIh0PYZzgSxiV7gw%3D%3D | Si | Through Hole | TO-247-3 | N-Channel | 1 Channel | 600 V | ="40 A" | 65 mOhms | - 30 V, + 30 V | 5 V | 74 nC | - 55 C | + 150 C | 250 W | Enhancement |  |  | Tube
726-IPW60R070CFD7XKS | IPW60R070CFD7XKSA1 | Infineon Technologies | https://www.mouser.fr/datasheet/2/196/Infineon_IPW60R070CFD7_DS_v02_01_EN-1732073.pdf | 3 559 In Stock | ="5,41 €" | RoHS Compliant |  | https://www.mouser.fr/ProductDetail/Infineon-Technologies/IPW60R070CFD7XKSA1?qs=xhbEVWpZdWdjqiIsmrAMfg%3D%3D | Si | Through Hole | TO-247-3 | N-Channel | 1 Channel | 600 V | ="31 A" | 57 mOhms | - 20 V, + 20 V | 3.5 V | 67 nC | - 55 C | + 150 C | 156 W | Enhancement |  | CoolMOS | Tube
78-SIHG73N60AE-GE3 | SIHG73N60AE-GE3 | Vishay Semiconductors | https://www.vishay.com/doc?91983 | 149 In Stock | ="5,72 €" | RoHS Compliant |  | https://www.mouser.fr/ProductDetail/Vishay-Semiconductors/SIHG73N60AE-GE3?qs=7EBvPakHacXKwrnkfhz3ug%3D%3D | Si | Through Hole | TO-247-3 | N-Channel | 1 Channel | 600 V | ="60 A" | 35 mOhms | - 30 V, + 30 V | 4 V | 394 nC | - 55 C | + 150 C | 417 W | Enhancement
726-IPZ65R065C7XKSA1 | IPZ65R065C7XKSA1 | Infineon Technologies | https://www.mouser.fr/datasheet/2/196/Infineon_IPZ65R065C7_DS_v02_01_en-1227347.pdf | 437 In Stock | ="5,45 €" | RoHS Compliant |  | https://www.mouser.fr/ProductDetail/Infineon-Technologies/IPZ65R065C7XKSA1?qs=WkdRfq4wf1OkonSQjxTHyw%3D%3D | Si | Through Hole | TO-247-4 | N-Channel | 1 Channel | 650 V | ="33 A" | 58 mOhms | - 20 V, + 20 V | 3 V | 64 nC | - 55 C | + 150 C | 171 W | Enhancement |  | CoolMOS | Tube
726-IPW60R060P7XKSA1 | IPW60R060P7XKSA1 | Infineon Technologies | https://www.mouser.fr/datasheet/2/196/Infineon_IPW60R060P7_DS_v02_01_EN-3362717.pdf | 1 063 In Stock | ="5,51 €" | RoHS Compliant |  | https://www.mouser.fr/ProductDetail/Infineon-Technologies/IPW60R060P7XKSA1?qs=HXFqYaX1Q2zGPImanxaIWw%3D%3D | Si | Through Hole | TO-247-3 | N-Channel | 1 Channel | 600 V | ="48 A" | 49 mOhms | - 20 V, + 20 V | 3 V | 67 nC | - 55 C | + 150 C | 164 W | Enhancement |  | CoolMOS | Tube
726-IPW65R048CFDAFKS | IPW65R048CFDAFKSA1 | Infineon Technologies | https://www.mouser.fr/datasheet/2/196/Infineon_IPW65R048CFDA_DS_v02_00_en-3362623.pdf | 226 In Stock | ="5,55 €" | RoHS Compliant |  | https://www.mouser.fr/ProductDetail/Infineon-Technologies/IPW65R048CFDAFKSA1?qs=4MqXaUMeF55hmz3f1nxZyg%3D%3D | Si | Through Hole | TO-247-3 | N-Channel | 1 Channel | 650 V | ="63.3 A" | 43 mOhms | - 20 V, + 20 V | 3.5 V | 270 nC | - 40 C | + 150 C | 500 W | Enhancement | AEC-Q100 | CoolMOS | Tube
863-NTHL067N65S3H | NTHL067N65S3H | onsemi | https://www.onsemi.com/PowerSolutions/product.do?id=NTHL067N65S3H | 82 In Stock | ="5,56 €" | RoHS Compliant By Exemption |  | https://www.mouser.fr/ProductDetail/onsemi/NTHL067N65S3H?qs=HBWAp0VN4RhjZzVYl%2F0lHQ%3D%3D | Si | Through Hole | TO-247-3 | N-Channel | 1 Channel | 650 V | ="40 A" | 67 mOhms | - 30 V, + 30 V | 4 V | 80 nC | - 55 C | + 150 C | 266 W | Enhancement |  |  | Tube
78-SIHG47N60AE-GE3 | SIHG47N60AE-GE3 | Vishay Semiconductors | https://www.vishay.com/doc?91888 | 314 In Stock | ="5,68 €" | RoHS Compliant |  | https://www.mouser.fr/ProductDetail/Vishay-Semiconductors/SIHG47N60AE-GE3?qs=EBLjwc9jJJsuPL3F2ra9fw%3D%3D | Si | Through Hole | TO-247-3 | N-Channel | 1 Channel | 600 V | ="43 A" | 56 mOhms | - 30 V, + 30 V | 4 V | 121 nC | - 55 C | + 150 C | 313 W | Enhancement |  |  | Tube
726-IPW60R070P6 | IPW60R070P6 | Infineon Technologies | https://www.mouser.fr/datasheet/2/196/Infineon_IPW60R070P6_DS_v02_00_en-1227467.pdf | 304 In Stock | ="5,74 €" | RoHS Compliant |  | https://www.mouser.fr/ProductDetail/Infineon-Technologies/IPW60R070P6?qs=PRAmo2HmaolgfmZiQ%2F7yqQ%3D%3D | Si | Through Hole | TO-247-3 | N-Channel | 1 Channel | 600 V | ="53.5 A" | 63 mOhms | - 20 V, + 20 V | 3.5 V | 100 nC | - 55 C | + 150 C | 391 W | Enhancement |  | CoolMOS | Tube
511-STWA65N60DM6 | STWA65N60DM6 | STMicroelectronics | https://www.st.com/resource/en/datasheet/stw65n60dm6.pdf | 589 In Stock | ="5,78 €" | RoHS Compliant By Exemption |  | https://www.mouser.fr/ProductDetail/STMicroelectronics/STWA65N60DM6?qs=byeeYqUIh0ORtBnZevpqfg%3D%3D | Si | Through Hole | TO-247-3 | N-Channel | 1 Channel | 600 V | ="38 A" | 71 mOhms | - 25 V, + 25 V | 3.25 V | 54 nC | - 55 C | + 150 C | 250 W | Enhancement |  | MDmesh | Tube

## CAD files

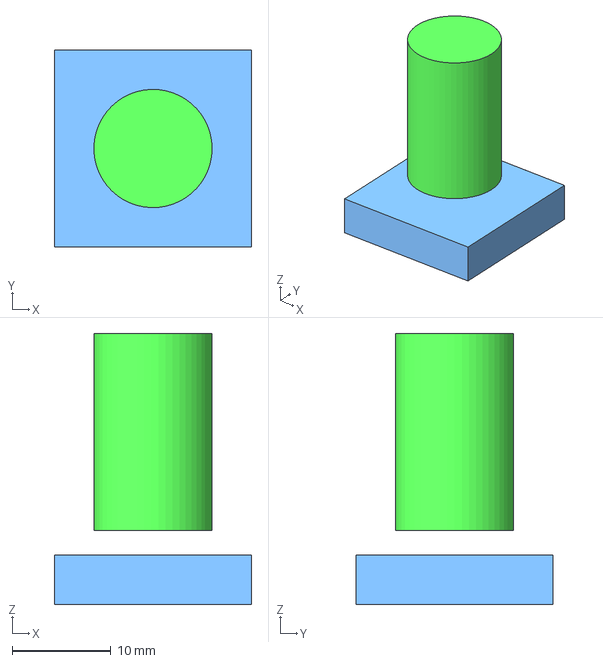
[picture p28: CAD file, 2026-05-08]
03_hw_design/02_schematic_and_bom/01_Schematics_BOM/DRAFT/LLC_DCDC_V4/creat_simple_stp_files/colored_assembly.step
20.0 x 20.0 x 27.5 mm
base
pillar

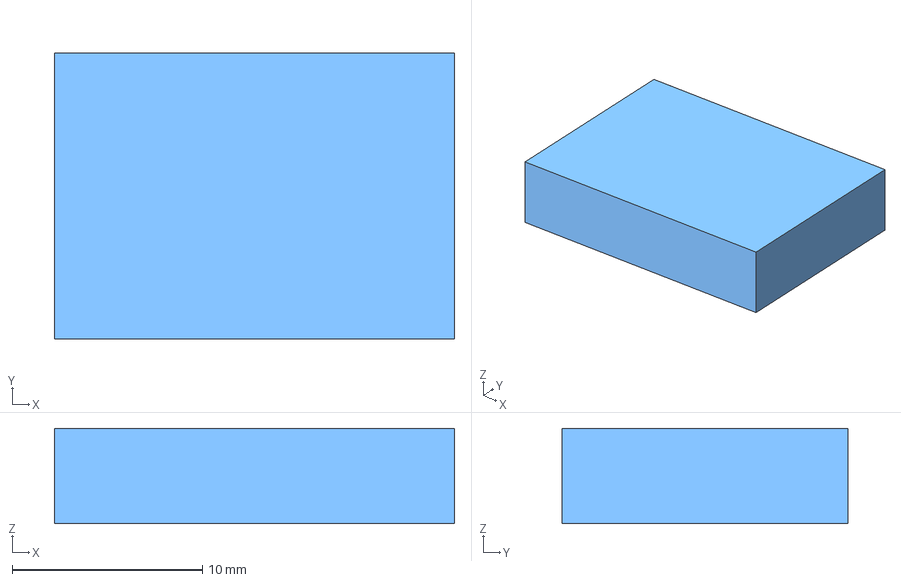
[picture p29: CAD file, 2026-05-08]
03_hw_design/02_schematic_and_bom/01_Schematics_BOM/LLC_DCDC_V5/creat_simple_stp_files/PG-TO247-3.step
21.0 x 15.0 x 5.00 mm

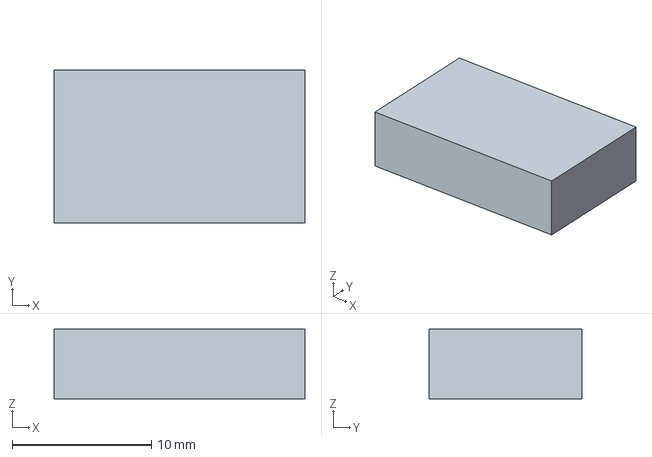
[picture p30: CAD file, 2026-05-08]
03_hw_design/02_schematic_and_bom/01_Schematics_BOM/LLC_DCDC_V5/creat_simple_stp_files/R46KI310050M1K.step
18.0 x 11.0 x 5.00 mm

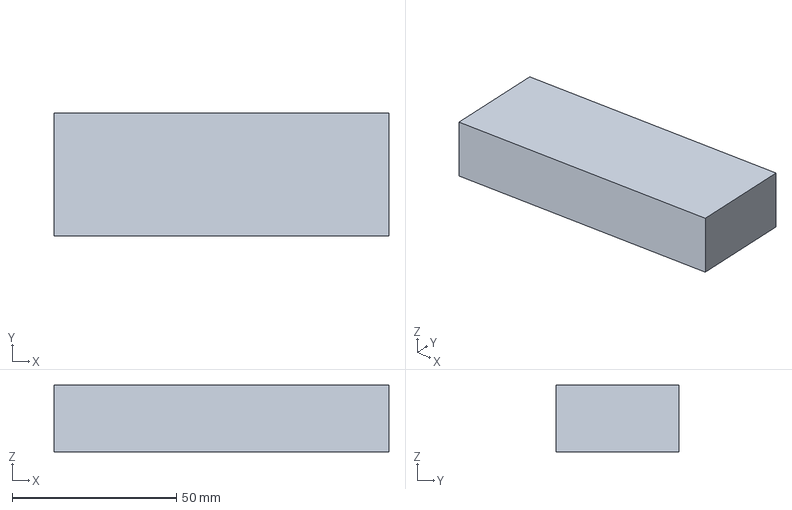
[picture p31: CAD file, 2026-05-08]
03_hw_design/02_schematic_and_bom/01_Schematics_BOM/DRAFT/LLC_DCDC_V4/creat_simple_stp_files/elp_102_20_38.step
102.0 x 37.5 x 20.3 mm

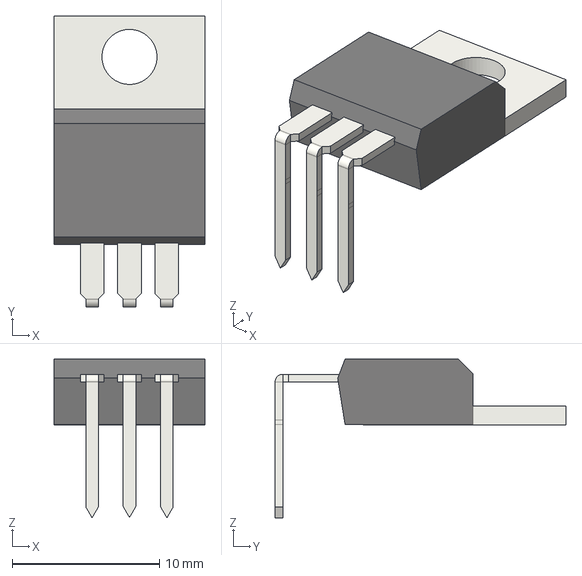
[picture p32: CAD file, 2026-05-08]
03_hw_design/02_schematic_and_bom/01_Schematics_BOM/LLC_DCDC_V5/creat_simple_stp_files/TO-220-3_Horizontal_TabDown.step
10.2 x 19.7 x 10.8 mm

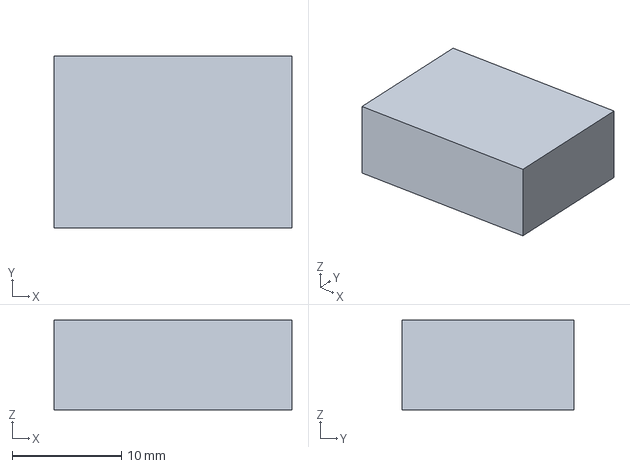
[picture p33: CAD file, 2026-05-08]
03_hw_design/02_schematic_and_bom/01_Schematics_BOM/DRAFT/LLC_DCDC_V4/creat_simple_stp_files/elp_22_6_16_V2.step
21.8 x 15.8 x 8.20 mm

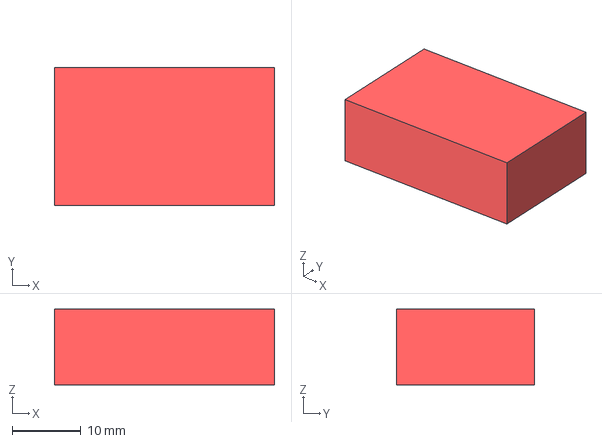
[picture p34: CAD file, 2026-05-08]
03_hw_design/02_schematic_and_bom/01_Schematics_BOM/LLC_DCDC_V5_Modifications/creat_simple_stp_files/EFDKS60K405D032LH.step
32.0 x 20.0 x 11.0 mm

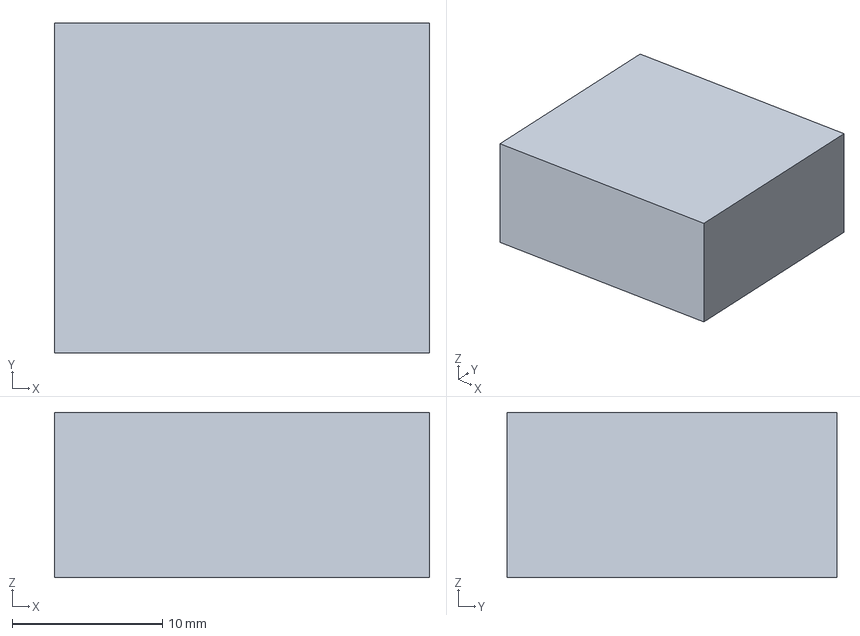
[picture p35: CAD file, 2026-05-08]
03_hw_design/02_schematic_and_bom/01_Schematics_BOM/DRAFT/LLC_DCDC_V4/creat_simple_stp_files/STM32.step
25.0 x 22.0 x 11.0 mm

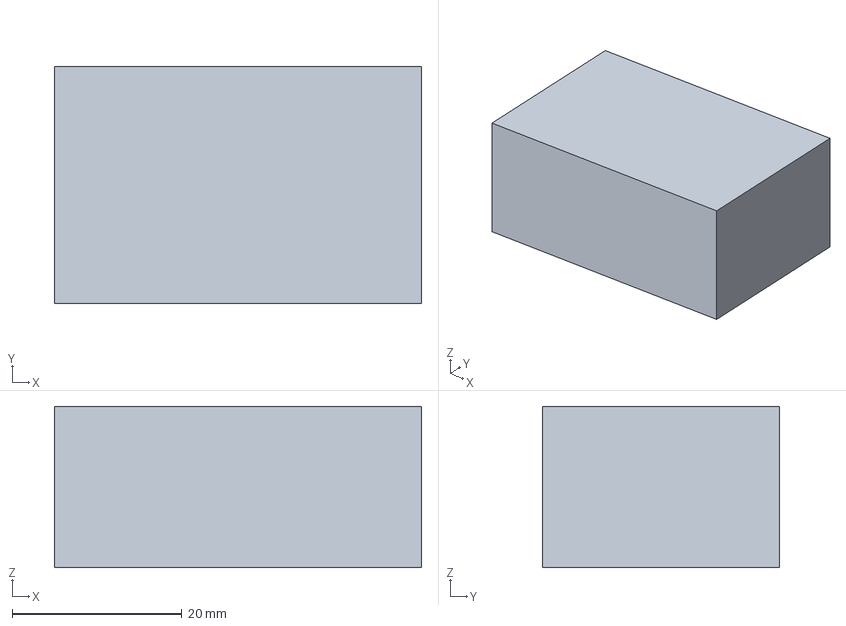
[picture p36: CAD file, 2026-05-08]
03_hw_design/02_schematic_and_bom/01_Schematics_BOM/LLC_DCDC_V5_Modifications/creat_simple_stp_files/elp_43_10_28_V2.step
43.2 x 27.9 x 19.0 mm

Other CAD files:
03_hw_design/02_schematic_and_bom/01_Schematics_BOM/LLC_DCDC_V5/creat_simple_stp_files/elp_22_6_16_V2.step
03_hw_design/02_schematic_and_bom/01_Schematics_BOM/LLC_DCDC_V5_Modifications/creat_simple_stp_files/elp_22_6_16_V2.step
03_hw_design/02_schematic_and_bom/01_Schematics_BOM/DRAFT/LLC_DCDC_V4/creat_simple_stp_files/elp_102_20_38_V2.step
03_hw_design/02_schematic_and_bom/01_Schematics_BOM/LLC_DCDC_V5/creat_simple_stp_files/PM5022-331M-RC.step
03_hw_design/02_schematic_and_bom/01_Schematics_BOM/LLC_DCDC_V5/creat_simple_stp_files/elp_102_20_38_V2.step
03_hw_design/02_schematic_and_bom/01_Schematics_BOM/LLC_DCDC_V5_Modifications/creat_simple_stp_files/PM5022-331M-RC.step
03_hw_design/02_schematic_and_bom/01_Schematics_BOM/LLC_DCDC_V5_Modifications/creat_simple_stp_files/elp_102_20_38_V2.step

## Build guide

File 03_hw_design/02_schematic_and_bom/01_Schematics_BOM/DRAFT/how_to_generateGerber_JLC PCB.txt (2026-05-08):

https://www.youtube.com/watch?v=b0cGPpCLrIc&t=208s

https://jlcpcb.com/help/article/how-to-generate-gerber-and-drill-files-in-kicad-7

https://jlcpcb.com/capabilities/pcb-capabilities

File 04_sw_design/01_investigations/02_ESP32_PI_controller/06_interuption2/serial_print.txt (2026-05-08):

I (283) main_task: Started on CPU0
I (293) main_task: Calling app_main()
Sample 0: 38980 µs
Sample 1: 39006 µs
Sample 2: 39106 µs
Sample 3: 39205 µs
Sample 4: 39306 µs
Sample 5: 39405 µs
Sample 6: 39505 µs
Sample 7: 39606 µs
Sample 8: 39705 µs
Sample 9: 39805 µs

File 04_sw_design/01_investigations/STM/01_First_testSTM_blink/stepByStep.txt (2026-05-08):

mini STM32F103C8T6-CH340 
I use only the USB CABLE 

DOWNLOAD and install WIND 64
https://www.st.com/en/development-tools/stm32cubeprog.html?dl=redirect
if you use defaut the bin folder must be 
C:\Program Files\STMicroelectronics\STM32Cube\STM32CubeProgrammer\bin

from admin cmd run 
C:\Users\Public\Documents>SystemPropertiesAdvanced
click In button Envir variables
add in user and system the path 
name = "Path"
value = "C:\Program Files\STMicroelectronics\STM32Cube\STM32CubeProgrammer\bin"

add https://github.com/stm32duino/BoardManagerFiles/raw/main/package_stmicroelectronics_index.json => done 
Search for STM32 and install "STM32 MCU based boards" by STMicroelectronics. => done 

In Arduino IDE 

| Option | Value |
| --- | --- |
| **Board** | `Generic STM32F1 series`  |
| **Board part number** | `BluePill F103C8` |
| **Upload method** | `CubeProgrammer serial'  |
| **Port** | Select COM6 for CH340 |

// Blink LED on PC13 (Blue Pill onboard LED)
void setup() {
  pinMode(PC13, OUTPUT);   // Built-in LED on PC13
}

void loop() {
  digitalWrite(PC13, LOW);   // LED ON (inverted logic)
  delay(500);
  digitalWrite(PC13, HIGH);  // LED OFF
  delay(500);
}

Press 
BOOT hold + Rest (not hold) + remove BOOT 
Flash the program 

==========> DONE 
RUNNING Program ... 
  Address:      : 0x8000000
Start operation achieved successfully

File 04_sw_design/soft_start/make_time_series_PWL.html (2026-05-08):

# FIRST TEST¶

In [5]:

import matplotlib.pyplot as plt
Freq = 100e3
rise_fall_time= 1e-6#100e-9
tarr =[]
varr =[]
time=0
vmin = 0
vmax=400
for i in range(3):
    # One cycle 
    #tarr.append(time)
    #varr.append(0)
    time = time +rise_fall_time
    tarr.append(time)
    varr.append(vmin)
    time = time +0.5/Freq-rise_fall_time
    tarr.append(time)
    varr.append(vmin)
    time = time +rise_fall_time
    tarr.append(time)
    varr.append(vmax)
    time = time +0.5/Freq-rise_fall_time
    tarr.append(time)
    varr.append(vmax)
    
plt.plot(tarr, varr)

Out[5]:

[<matplotlib.lines.Line2D at 0x27eb84b5090>]

No description has been provided for this image

# 0 400V¶

In [49]:

import matplotlib.pyplot as plt
import pandas as pd 
Freq = 100e3
rise_fall_time= 100e-9
tarr =[]
varr =[]
time=0
vmin = 0
vmax=400

start_time_off=200e-6
dt_each_cycle= 1/Freq
for i in range(100):
    # One cycle 
    #tarr.append(time)
    #varr.append(0)
    time = time +rise_fall_time
    tarr.append(time)
    varr.append(vmin)
    time = time +0.5/Freq-rise_fall_time
    tarr.append(time)
    varr.append(vmin)
    time = time +rise_fall_time
    tarr.append(time)
    varr.append(vmax)
    time = time +0.5/Freq-rise_fall_time
    tarr.append(time)
    varr.append(vmax)
    time = time +rise_fall_time
    tarr.append(time)
    varr.append(vmin)
    time = time +start_time_off
    tarr.append(time)
    varr.append(vmin)
    start_time_off-=dt_each_cycle
    if start_time_off < 1/Freq:
        break
total_time_0= tarr[-1]
plt.figure( figsize=(20,2))
plt.plot(tarr, varr)
plt.xlabel("time s")
plt.ylabel("voltage V")
plt.grid()
plt.savefig("voltage_plot_soft_start.jpg")
plt.show()

df = pd.DataFrame(tarr)
df[1]= varr
#df.to_csv("voltage_plot_soft_start.txt", sep = "\t", index= False)

No description has been provided for this image

In [ ]:

In [50]:

tarr =[]
varr =[]
time=0
for i in range(3000):
    # One cycle 
    #tarr.append(time)
    #varr.append(0)
    time = time +rise_fall_time
    tarr.append(time)
    varr.append(vmin)
    time = time +0.5/Freq-rise_fall_time
    tarr.append(time)
    varr.append(vmin)
    time = time +rise_fall_time
    tarr.append(time)
    varr.append(vmax)
    time = time +0.5/Freq-rise_fall_time
    tarr.append(time)
    varr.append(vmax)
    if time >=total_time_0:
        break

total_time_0= tarr[-1]
plt.figure( figsize=(20,2))
plt.plot(tarr, varr)
plt.xlabel("time s")
plt.ylabel("voltage V")
plt.grid()
plt.savefig("voltage_plot_NO_soft_start.jpg")
plt.show()

df = pd.DataFrame(tarr)
df[1]= varr
#df.to_csv("voltage_plot_NO_soft_start.txt", sep = "\t", index= False)

No description has been provided for this image

# High Low and dead time¶

### No SOFT START¶

No description has been provided for this image

In [239]:

def signalPWMold(Freq = 100e3, simTime = 1e-3, rise_fall_time= 1e-6, dead_time= 2e-6 , deadTime=0) : 
    phase = True 
    T= 1/Freq
    N = int(simTime/T)
    arr = np.zeros((N*10, 3))
    nmode= 4
    phasei=1
    for i in range(len(arr)):
        if phase : 
            phasei = 1
        else: 
            phasei = 2
        if i%nmode==0:
            if i == 0:
                arr[i][0]=0+rise_fall_time
                arr[i][phasei]=1
                continue 
            arr[i][0]=arr[i-1][0]+rise_fall_time
            arr[i][phasei]=1
        if i%nmode==1:
            arr[i][0]=arr[i-1][0]+T/2-dead_time-2*rise_fall_time
            arr[i][phasei]=1
        if i%nmode==2:
            arr[i][0]=arr[i-1][0]+rise_fall_time
            arr[i][phasei]=0
        if i%nmode==3:
            arr[i][0]=arr[i-1][0]+ dead_time
            arr[i][phasei]=0
            phase = not phase
            #print(phase)
    return arr

A= signalPWMold(simTime = 30e-6)
plt.plot(A.T[0], A.T[1])
plt.plot(A.T[0], A.T[2])
#plt.xlim([0,30e-6])

Out[239]:

[<matplotlib.lines.Line2D at 0x27ecc492990>]

No description has been provided for this image

In [242]:

def signalPWM1(Freq = 100e3, simTime = 1e-3, rise_fall_time= 1e-6, dead_time= 2e-6 , deadTime=0) : 
    phase = True 
    T= 1/Freq
    N = int(simTime/T)
    arr = np.zeros((N*10, 3))
    nmode= 4
    phasei=1
    for i in range(len(arr)):
        if phase : 
            phasei = 1
        else: 
            phasei = 2
        match i%nmode:
            case 0:
                if i >0:
                    arr[i][0]=arr[i-1][0]+ dead_time
                    phase = not phase
            case 1:
                arr[i][0]=arr[i-1][0]+rise_fall_time
                arr[i][phasei]=1
            case 2:
                arr[i][0]=arr[i-1][0]+T/2-dead_time-2*rise_fall_time
                arr[i][phasei]=1
            case 3: 
                arr[i][0]=arr[i-1][0] +rise_fall_time

    return arr

A= signalPWM1(simTime = 30e-6)
plt.plot(A.T[0], A.T[1])
plt.plot(A.T[0], A.T[2])
#plt.xlim([0,30e-6])

Out[242]:

[<matplotlib.lines.Line2D at 0x27ecc7d2d50>]

No description has been provided for this image

No description has been provided for this image

In [266]:

rise_fall_time= 10e-9
dead_time= 50e-9

A= signalPWM1(simTime = 4e-3, rise_fall_time=rise_fall_time,dead_time= dead_time, Freq = 156e3 )
plt.figure( figsize=(20,2))
plt.plot(A.T[0], A.T[1])
plt.plot(A.T[0], A.T[2])

plt.xlabel("time s")
plt.ylabel("voltage V")
plt.grid()
plt.show()
plt.savefig("voltage_plot_soft_start.jpg")

plt.show()

df = pd.DataFrame(A)
#df = df*10
df.iloc[:, 1:3] =df.iloc[:, 1:3]*10
df[[0,1]].to_csv("voltage_plot_No_soft_start_H.txt", sep = "\t", index= False, header = None)
df[[0,2]].to_csv("voltage_plot_No_soft_start_L.txt", sep = "\t", index= False, header = None)

Vh=10
plt.figure( figsize=(20,2))
plt.plot(A.T[0], A.T[1])
plt.plot(A.T[0], A.T[2])
plt.xlim([0,30e-6])
plt.xlabel("time s")
plt.ylabel("voltage V")
plt.grid()
plt.show()

No description has been provided for this image

<Figure size 640x480 with 0 Axes>

No description has been provided for this image

In [ ]:

In [267]:

fig, ax= plt.subplots( figsize=(20,2))
df.loc[:10,1:3].plot(ax=ax)

#plt.xlim([0,30e-6])
plt.xlabel("time s")
plt.ylabel("voltage V")
plt.grid()
plt.show()

No description has been provided for this image

### SOFT start strategy 1¶

In [275]:

def signalPWM2(Freq = 100e3, simTime = 1e-3, rise_fall_time= 1e-6, dead_time= 2e-6 , deadTime=0) : 
    phase = True 
    T= 1/Freq
    N = int(simTime/T)
    arr = np.zeros((N*10, 3))
    nmode= 4
    phasei=1

    Tquite=10*T
    count = 0 
    
    for i in range(len(arr)):
        if phase : 
            phasei = 1
        else: 
            phasei = 2
        match i%nmode:
            case 0:
                if i >0:
                    arr[i][0]=arr[i-1][0]+ dead_time
                    phase = not phase
            case 1:
                arr[i][0]=arr[i-1][0]+rise_fall_time
                arr[i][phasei]=1
            case 2:
                arr[i][0]=arr[i-1][0]+T/2-dead_time-2*rise_fall_time
                arr[i][phasei]=1
            case 3: 
                arr[i][0]=arr[i-1][0] +rise_fall_time
        if i%(nmode)==2 and phasei == 2:
            #print(i)
            if Tquite > T and i> 0 :
                arr[i][1]=0
                arr[i][2]=1
                arr[i][0]=arr[i-1][0]+Tquite
                Tquite=Tquite-T

    return arr

fig, ax= plt.subplots( figsize=(20,2))

A= signalPWM2(simTime = 24e-6)
plt.plot(A.T[0], A.T[1])
plt.plot(A.T[0], A.T[2])
#plt.xlim([0,130e-6])

Out[275]:

[<matplotlib.lines.Line2D at 0x27ecd2f8cd0>]

In [276]:

df

Out[276]:

| 0 | 1 | 2
0 | 0.000000e+00 | 0.0 | 0.0
1 | 1.000000e-08 | 10.0 | 0.0
2 | 3.145128e-06 | 10.0 | 0.0
3 | 3.155128e-06 | 0.0 | 0.0
4 | 3.205128e-06 | 0.0 | 0.0
6235 | 5.342449e-03 | 0.0 | 0.0
6236 | 5.342499e-03 | 0.0 | 0.0
6237 | 5.342509e-03 | 0.0 | 10.0
6238 | 5.345644e-03 | 0.0 | 10.0
6239 | 5.345654e-03 | 0.0 | 0.0

6240 rows × 3 columns

In [277]:

fig, ax= plt.subplots( figsize=(20,2))

A= signalPWM2(simTime = 24e-6)
plt.plot(A.T[1])
plt.plot( A.T[2])
plt.grid()

In [278]:

fig, ax= plt.subplots( figsize=(20,2))

A= signalPWM2(simTime = 230e-6)
plt.plot(A.T[0], A.T[1])
plt.plot(A.T[0], A.T[2])
#plt.xlim([0,130e-6])

Out[278]:

[<matplotlib.lines.Line2D at 0x27eccfd3c50>]

In [279]:

rise_fall_time= 10e-9
dead_time= 50e-9

A= signalPWM2(simTime = 4e-3, rise_fall_time=rise_fall_time,dead_time= dead_time, Freq = 156e3 )
plt.figure( figsize=(20,2))
plt.plot(A.T[0], A.T[1])
plt.plot(A.T[0], A.T[2])

plt.xlabel("time s")
plt.ylabel("voltage V")
plt.grid()
plt.show()
plt.savefig("voltage_plot_soft_start.jpg")

plt.show()

df = pd.DataFrame(A)
#df = df*10
df.iloc[:, 1:3] =df.iloc[:, 1:3]*10
df[[0,1]].to_csv("voltage_plot_soft_start_H.txt", sep = "\t", index= False, header = None)
df[[0,2]].to_csv("voltage_plot_soft_start_L.txt", sep = "\t", index= False, header = None)

plt.figure( figsize=(20,2))
plt.plot(A.T[0], A.T[1])
plt.plot(A.T[0], A.T[2])
plt.xlim([0,120e-6])
plt.xlabel("time s")
plt.ylabel("voltage V")
plt.grid()
plt.show()

No description has been provided for this image

<Figure size 640x480 with 0 Axes>

No description has been provided for this image

No description has been provided for this image

In [ ]:

### SOFT START 2¶

In [312]:

def signalPWM3(Freq = 100e3, simTime = 1e-3, rise_fall_time= 0.2e-6, dead_time= 0.5e-6 , deadTime=0) : 
    phase = True 
    T= 1/Freq
    N = int(simTime/T)
    arr = np.zeros((N*10, 3))
    nmode= 4
    phasei=1

    Trat=0.05
    T1=Trat*T
    T2=(1-Trat)*T
    
    n=1

    print(simTime , Freq)
    for i in range(len(arr)):
        if phase : 
            phasei = 1
        else: 
            phasei = 2
        match i%nmode:
            case 0:
                if i >0:
                    arr[i][0]=arr[i-1][0]+ dead_time
                    phase = not phase
            case 1:
                arr[i][0]=arr[i-1][0]+rise_fall_time
                arr[i][phasei]=1
            case 2:
                if phasei==1:
                    Tuse = T1
                    n+=1
                    if n%10 ==0 and Trat < 0.5:
                        Trat+=0.005
                        T1=Trat*T
                        T2=(1-Trat)*T
                                            
                else :
                    Tuse = T2
                arr[i][0]=arr[i-1][0]+Tuse-dead_time-2*rise_fall_time
                arr[i][phasei]=1
            case 3: 
                arr[i][0]=arr[i-1][0] +rise_fall_time

    return arr

A= signalPWM3(simTime = 30e-6)
plt.plot(A.T[0], A.T[1])
plt.plot(A.T[0], A.T[2])
#plt.xlim([0,30e-6])

3e-05 100000.0

Out[312]:

[<matplotlib.lines.Line2D at 0x27ecdaafb10>]

No description has been provided for this image

In [313]:

fig, ax= plt.subplots( figsize=(20,2))

A= signalPWM3(simTime = 200e-6)
plt.plot(A.T[0], A.T[1])
plt.plot(A.T[0], A.T[2])
#plt.xlim([0,130e-6])

0.0002 100000.0

Out[313]:

[<matplotlib.lines.Line2D at 0x27ed2622210>]

In [315]:

rise_fall_time= 10e-9
dead_time= 50e-9

A= signalPWM3(simTime = 6e-3, rise_fall_time=rise_fall_time,dead_time= dead_time, Freq = 156e3 )
plt.figure( figsize=(20,2))
plt.plot(A.T[0], A.T[1])
plt.plot(A.T[0], A.T[2])

plt.xlabel("time s")
plt.ylabel("voltage V")
plt.grid()
plt.show()
plt.savefig("voltage_plot_soft_start.jpg")

plt.show()

df = pd.DataFrame(A)
#df = df*10
df.iloc[:, 1:3] =df.iloc[:, 1:3]*10
df[[0,1]].to_csv("voltage_plot_soft_start_H.txt", sep = "\t", index= False, header = None)
df[[0,2]].to_csv("voltage_plot_soft_start_L.txt", sep = "\t", index= False, header = None)

Vh=10
plt.figure( figsize=(20,2))
plt.plot(A.T[0], A.T[1])
plt.plot(A.T[0], A.T[2])
plt.xlim([0,30e-6])
plt.xlabel("time s")
plt.ylabel("voltage V")
plt.grid()
plt.show()

0.006 156000.0

No description has been provided for this image

<Figure size 640x480 with 0 Axes>

No description has been provided for this image

In [ ]:

########## start with 0.1 decrease with 0.01

No description has been provided for this image

In [316]:

########## start with 0.05 decrease with 0.005

No description has been provided for this image

##### with load¶

No description has been provided for this image

In [ ]:

def soft_start_sequence(Fstart, Ftarget, simTimeMax, burst_init_pulses, pause_init, burst_step, pause_step, freq_step, current_limit): # Fstart: starting switching frequency (e.g. > resonance) # Ftarget: final desired switching freq # burst_init_pulses: # pulses in first burst # pause_init: pause between bursts (in us, or time units) # burst_step: how many more pulses to add each round # pause_step: how much to reduce pause each round # freq_step: how much to drop freq (toward resonance) each round # current_limit: max allowed sensed current freq = Fstart burst_pulses = burst_init_pulses pause_time = pause_init time_elapsed = 0.0 while time_elapsed < simTimeMax: # 1) burst block for p in range(burst_pulses): if current_sense() > current_limit: return “abort or slow down” # Optionally wait until half-bridge node is near zero (if you can sample) # simple blanking delay: blanking_delay() drive_halfbridge_cycle(freq) # increment time_elapsed by one period (1/freq) time_elapsed += 1.0 / freq # 2) pause wait(pause_time) # time in same units time_elapsed += pause_time # 3) optional check of output voltage (if measuring) if read_output_voltage() >= threshold: break # close to target, exit to continuous mode # 4) update parameters burst_pulses += burst_step pause_time = max(0, pause_time - pause_step) freq = max(Ftarget, freq - freq_step) # Now switch to continuous operation (normal PWM or frequency modulation) continuous_run()

In [ ]:

In [ ]:

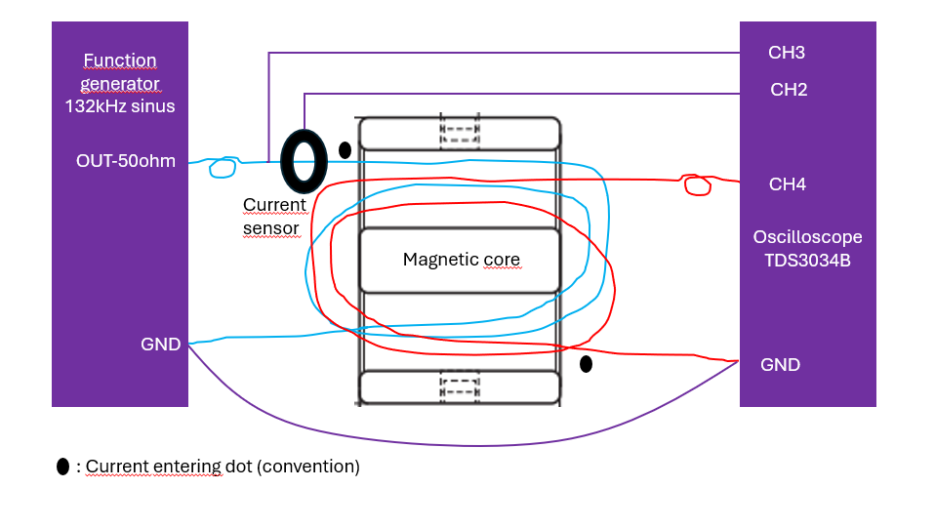
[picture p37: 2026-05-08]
03_hw_design/01_design_justification/07_power_supp/01_FlyBack/figs/setup.png

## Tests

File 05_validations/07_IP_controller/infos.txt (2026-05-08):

FYI : SYNCH IC of MOS SEC H IS NOK (HS)
Vin = 48.9
Vout = 9.21
CH1 = Vds low primary 
CH3 = Vout/GND 
CH4 = VGS of low second

import pandas as pd
df = pd.read_csv("data/2025-12-12_11-18-16-855.csv")
df.head()
Ts= df.Ts.iloc[0]
CH1 = df.CH1.values
CH1 = CH1-CH1[200].mean()
plt.plot(CH1)

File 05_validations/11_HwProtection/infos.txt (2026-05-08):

PI_V20_fix_freq_100khz
81V around vinp 

CH1 = VDS LOW SIDE PRIM 
CH4 = Vout copparator x10
check the HW protection problem
2026-02-15_12-10-19-208

shot 2
2026-02-15_12-11-41-625

CH3 = out of ampli isolated of Vout measurement 
2026-02-15_12-15-08-852

2026-02-15_12-20-10-536
CH3 = PB11 (HW protection disable)

PI_V21_fix_freq_100khz_HWprot_Correction
no hw protection problem 
ch3= open air 

disable HW protection of secondary voltage 
3.011 as ref to avoid 2.8xxv 
for the moment
to 3.292v max 

2026-02-15_12-54-49-324
CH4 = Vout copparator x10
a lot of noise 

2026-02-15_13-14-37-137
prim fault 
res parallel 55k see excel file 
CH4 = Vo the resistor 
ch3 = out comparator 
ch1 = vgs or high side 

2026-02-15_13-14-37-137

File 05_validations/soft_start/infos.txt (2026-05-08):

380v inp 

actual start 
CH1= Vds 
CH2= Inp current 
2026-02-10_16-05-49-985

CH1 = V_Cr (Gnd of prob = HVn)
2026-02-10_16-09-27-087

CH1 = V_Lr (Gnd = Trans side , red = Drain side)
2026-02-10_16-12-50-922.png

79.7V vin 
CH1 = Vds 
pld sw 
PI_V17_periode_decreasing_control
2026-02-10_16-37-38-586

new sw PI_V18....
2026-02-10_16-42-22-078.png

Freq 
2026-02-10_16-43-28-557.png
2026-02-10_16-44-34-558

380V
2026-02-10_16-47-25-801.png

SW 19 
2026-02-10_16-59-38-669

CH4 = Voutput of comparator 
2026-02-10_17-04-17-293
no trig but noise !!!

=======================================
PI_V21_fix_freq_100khz
load of bouillard 2200w noire
27.2 ohm measur
2026-02-15_13-35-20-878.png
what is this mesterious frequency of 1.45khz :) hhh 

CH1 = Vtransfo x 100 prim low side
CH4 = vgs of prim low side x10

2026-02-15_13-42-54-486
ch2 = current input HVP 
trans voltage is null initially 

regime etablie ce que le transfo voir 
2026-02-15_13-45-43-950

ch4 = vds of low side secondary 
2026-02-15_13-47-24-481

2026-02-15_13-50-39-607
ch4 = vd-d heigh side low side secondary 
voltage everwhe = max = around 404V

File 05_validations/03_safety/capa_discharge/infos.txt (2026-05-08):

Active discharge load 27ohm 
2026-02-14_10-38-22-329

Only flyback with fans
2026-02-14_10-43-22-253.png

only flyback no fans 
2026-02-14_10-46-46-669

540kohm between EN to GND or 12V 
flyback alwase on ==> NOK

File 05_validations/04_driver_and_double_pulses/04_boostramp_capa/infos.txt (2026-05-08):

bootsrap circuit 
1u + US2MA + 2.15 ohm 
UDC =48.86V 
R_load (Between D and S of heigh side) = 470kohm

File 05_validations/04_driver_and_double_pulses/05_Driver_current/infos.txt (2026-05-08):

Vin = 48.03V
Vout = 8.03V (regulation)
Vflyback= 11.35v

CH4 = Vgs of MOS LOW SIDE PRIMARY 
CH2 = Ioutput of the driver (Ig in the jumper) of the same mos
No load Rg = 3Ohm 
2025-12-31_09-53-33-832.csv 
Secondary R_Tmin= 20k ==> Ton_min = 2us 
see 
2025-12-31_09-57-54-241.png
Turn on off see next screenshoots 

Freq of regulation 
2025-12-31_10-09-07-719.png

-------------------------------
CH4 = Vgs of MOS LOW SIDE PRIMARY 
CH2 = Ioutput of the driver (Ig in the jumper) of the high side mos (prim)

Driver: VDD LOW SIDE = 11.35 VDD HEIGH SIDE = 10.79 
2025-12-31_10-15-14-895.png

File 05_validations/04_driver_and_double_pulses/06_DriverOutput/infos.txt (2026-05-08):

2026-02-14_13-56-32-214
48.11 393.5v
no load 

first load  52.1 (chauffage) 
2026-02-14_13-58-48-201

load2 36
2026-02-14_13-59-51-527
2026-02-14_14-00-43-431

load 3 24.5 (chauffage 2500)
2026-02-14_14-01-25-664

load 12.8 (chauffage 2500 +bouillard 1800-2200w)
2026-02-14_14-07-22-440

load 9.2 ohm (chauffage 2500 +bouillard 1800-2200w +bouillard rouge 2200w)
2026-02-14_14-09-33-703

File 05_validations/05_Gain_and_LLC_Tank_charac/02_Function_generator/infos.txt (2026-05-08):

all mos are removed 
Input = Middle point / HV- = 2 voltage : One DC + one AC , why DC voltage will polarise this point to block the bootstramp diode ==> so we can forget this branch 
Output = Vd1_d2 = Voltage between drains of each secondary mosfet footprint (no mos), composed voltage 
Charge = 1963 ohm 
Freq khz	CH1 pp	CH2 pp	CH2/CH1	Res ? 
162.1	8.45	6.52	0.771597633	
151.7	8.25	6.46	0.783030303	
139.9	7.95	6.42	0.80754717	
129.4	7.65	6.34	0.82875817	
121.3	7.4	6.22	0.840540541	
109.9	7.2	6.12	0.85	
101.7	6.65	6	0.902255639	
90.93	6	5.76	0.96	
80.99	5.02	5.52	1.099601594	
70.35	3.98	5.22	1.311557789	
61.25	2.78	4.8	1.726618705	
50	1.11	4.24	3.81981982	
47	0.42	4	9.523809524	res
42	1.05	3.52	3.352380952	
37	2.2	3.12	1.418181818	

Charge 10.1ohm oscillo
Freq khz	CH1 pp	CH2 pp	CH2/CH1	Res ? 
160.6	5.3	3.74	0.705660377	
151.8	5.2	3.74	0.719230769	
141.4	5.05	3.78	0.748514851	
131.3	4.85	3.74	0.771134021	
121.6	4.46	3.76	0.843049327	
110	4.2	3.78	0.9	
101.2	4	3.72	0.93	
90.55	3.72	3.66	0.983870968	
80.42	3.28	3.64	1.109756098	
70.31	2.8	3.52	1.257142857	
61.93	2.24	3.44	1.535714286	
52.38	1.48	3.05	2.060810811	res
49.74	1.45	2.99	2.062068966	
42.19	1.89	2.69	1.423280423	
36.3	2.86	2.38	0.832167832	

No load (10 meg)
Res = 46.83
390mV CH1 
3.75V CH2
Res = 2026-01-09_14-53-20-949.png
Res-1 = 2026-01-09_14-53-54-177.png
Res-2 = 2026-01-09_14-54-23-273.png
Res+1 = 2026-01-09_14-54-54-084.png
Res+2 = 2026-01-09_14-55-14-291.png
100kHz =2026-01-09_14-56-06-802.png

Short circuit secondary 
CH1 = Vin (12DC Battery + GBF, meas AC) 
CH2 = Current In 
see 2026-01-09_15-13-25-289.png
kHz	Vpp	mA	CH2->CH1 °	Z= Vpp/mA
160.3	3.29	343	-87.29	9.591836735
138.6	2.55	353	-90.53	7.223796034
120.5	1.84	357	-97.59	5.154061625
110.2	1.35	360	-102.6	3.75
100.7	0.805	360	-99.75	2.236111111
86.57	0.375	363	-119.6	1.033057851
81.58	0.52	362	94.11	1.436464088
60.5	2.04	359	92.17	5.682451253

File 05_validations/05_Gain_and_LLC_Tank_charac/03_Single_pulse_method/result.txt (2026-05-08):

Lr 2 layers of 0.2mm => gap of 0.8mm
Lr = 21uH
Lm of one layer 0.05mm => gap of 0.1mm
Lm = 83uH

Fr = 1/(sqrt(21e-6*120e-9)*2*pi) = 100258.190321 Hz 
Lm/Lr = Ln = 83/21=3.95

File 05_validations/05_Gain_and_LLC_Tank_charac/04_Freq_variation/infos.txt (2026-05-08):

# vin 48.08v vbat 12.08v  vout 5.98v  150khz  no load 
vds of secondary low side 
2026-01-08_18-08-35-224
vds of secondary heigh side 
2026-01-08_18-11-58-206

vds of secondary low side load 52.7 ohm
2026-01-08_18-14-19-064
vds of secondary low side load 36.1 ohm
2026-01-08_18-15-00-617.png
vds of secondary low side load 22.6 ohm
2026-01-08_18-15-57-961
vds of secondary low side, Vin 349.9V Vout 40.81V no load 
2026-01-08_18-20-50-509
load 52.7 ohm
2026-01-08_18-23-12-315

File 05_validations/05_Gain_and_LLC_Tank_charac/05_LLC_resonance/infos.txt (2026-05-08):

Vin = 96.2 V
Cmd relay = 6v 
CH1 = ISOLATED PROB x 100 Vcapa
CH2 = Current prob = I_relay vers point milieu 
CH3 = isolated I_shunt 50 ohm 
CH4 = Vdd (Vout composé, drain heigh - drain low x 10 no isolated)

Lm + Lr 
2026-01-12_17-05-29-193.png2026-01-12_17-08-29-072.png => 5*8.93 = 44.65kHz 

shot 2 
2026-01-12_17-09-27-883

shot 3
2026-01-12_17-10-50-655

vin = 145.2V
No current to calibrate sensor for 145.2v
0v for ch1 is to done
2026-01-12_17-17-01-155

shot1 145v
2026-01-12_17-17-57-259

2026-01-12_17-18-47-334 8.83khz*5 = 44.15khz

shot 2 
2026-01-12_17-20-05-266

shot 3
2026-01-12_17-20-48-790

Short circuit Lm 
only Lr + Cr

shot 1
2026-01-12_17-26-26-541

shot 2
2026-01-12_17-28-05-327
2026-01-12_17-29-13-721.png==> 17.2*5= 86khz
17.3

shot 3 
2026-01-12_17-29-53-710.txt

shot 4
2026-01-12_17-30-26-003.png

short circuit Lr 
shot 1
2026-01-12_17-35-52-092.csv
11.8*4= 47.2kHz 

shot 2
2026-01-12_17-37-13-951.png

shot 3
2026-01-12_17-37-55-165.csv

OV calibration (relay claused 
2026-01-12_17-39-34-446.png

current sensor calibration 
Lr + Lm + Cr
Setup 2 (see photo) 
2026-01-12_17-47-35-714.png

shot 2
transitory
2026-01-12_17-48-09-795.png

shot3
Res 20k fumé (done) 
2026-01-12_17-49-19-711.png

Lm+Lr+Cr ==> 44.15khz
Lr+Cr ==> 86khz (short Lm)
Lm + Cr ==> 47.2kHz  (short Lr)

----------------------------
CH3 = 19.68 k ohm instead of 50
2026-01-17_17-08-05-537.csv
2026-01-17_17-09-09-451

no transfo ch3 = 1mega 
2026-01-17_17-12-54-609

No transfo ch3 = 50 ohm 
2026-01-17_17-14-04-627.csv
2026-01-17_17-14-32-620
2026-01-17_17-15-22-907

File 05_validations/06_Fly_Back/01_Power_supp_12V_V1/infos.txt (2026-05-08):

see video for this flyback 
https://www.youtube.com/watch?v=GICw2HpsInU
2025-12-21_12-40-09-517.png
Vin = 307.8V
Vout = 12.21V
Rload (out) = 10 ohm x 4
CH1 = Islated sensor = Vp_trans
CH2 = Current of the primary of the trans 
CH3 = Vs of the trans (x10)

2025-12-21_12-42-45-746.png QUALIBRATION (0V 0A)

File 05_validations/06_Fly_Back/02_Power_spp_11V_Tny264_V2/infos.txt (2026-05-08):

TNY264PN (NOT 254 i'm sur) power supp 

Vin = (no meas)
Vout = 11.14V
Rload (out) = 10 ohm x 4
CH1 = Islated sensor = Vp_trans
CH2 = Current of the primary of the trans 
CH3 = Vs of the trans (x10)

2025-12-21_13-59-23-559 0A 0V 

2025-12-22_10-48-55-702 0 A output no load
duty cycle 100*0.840/106 = 0.79%

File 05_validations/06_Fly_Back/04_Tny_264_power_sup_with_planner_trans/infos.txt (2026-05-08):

TNY264PN (NOT 254 i'm sur) power supp 

Vin = (no meas)
Vout = 11.14V
Rload (out) = 10 ohm x 4
CH1 = Islated sensor = Vp_trans
CH2 = Current of the primary of the trans 

No load
vout 11.16v
vin 313.1v
2025-12-22_11-34-38-340

Load 
Vout 11.14V
2025-12-22_11-42-20-845.png
2025-12-22_11-43-23-012.png
...
2025-12-22_11-44-55-477.png

v = L di/dt
L = v/(di/dt) =1e6*280/(209e-3/1.48e-6)=1982.77uH
small signal L = 2320.032 uH
Theorical value 5.2*26**2= 3515.2uH

2025-12-22_12-01-03-789.png
CH2 = OUTPUT CURRENT sens du courant est l'invere de la diode (il faut ajouté - pour avoir le vourant de la diode 

WITH LOAD
CH2 = Ip of trans
Vin = 324v
2025-12-22_12-23-51-444.csv

Vin = 324v
2025-12-22_12-23-51-444.csv

Vin = 396.6v
2025-12-22_12-28-08-717

Vin = 387V
Load = 20ohm instead of 40Ohm (~500mA)
2025-12-22_12-30-58-426.png
the TNY264 make reset each 852ms
2025-12-22_12-33-02-043.png

Vin = 414V
Load 20 Ohm 
2025-12-22_12-40-33-094.png

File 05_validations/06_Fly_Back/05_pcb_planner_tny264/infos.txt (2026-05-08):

Trans 
Np = 8+18
Ns = 4
CH1 = vp of trans 
CH2 = Ip of the trans 
output around 11v (ziner 10v +1)
load 40 ohm 

low voltage like 340V or 320...
2025-12-23_08-54-28-772.png

419v
2025-12-23_08-56-59-168

vin 47.50
2026-01-03_20-13-08-982.csv
CH4 Vds of IC TNY ( no isolated x10)
CH2 = Current of the Primary 
CH3 = Kathode / Gnd (secondary) :  no isolated x1
2026-01-03_20-17-37-295.png 4.3u 4.3/7.24(138khz)=59% (max duty)

TNY280 47.5 V 
2026-01-03_20-25-49-597

Vin out 97 11.28
CH1 = vp of trans (HV+/D)
CH2 = Ip of the trans 
2026-01-03_20-37-01-334

Vin out 350.6 11.28
2026-01-03_20-43-43-679.csv

48V default 
CH4 x10 Vp (already x10 in setup)
CH2 Ip 
2026-01-04_12-16-21-026

tny264 with 100nF capa + diode change using 36
349.6v in
5.878bp (5.877 for48v)
11.35v out
2026-01-04_13-05-46-636
ch1= vds
580ns 350v supp 250mA
v = L di/dt ==>L =1e6*350/(0.25/580e-9)=812uH???

426.9V
2026-01-04_13-13-59-933

in out 350.5 11.35
Load Fan 12v/0.13A 1.6w (datasheet)
2026-01-04_13-38-06-701.csv

in out 350.8 11.34
load 2 x Fan 12v/0.13A 1.6w (datasheet)
2026-01-04_13-52-05-845.csv

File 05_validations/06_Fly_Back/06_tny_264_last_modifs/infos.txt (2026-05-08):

0V 0A 
2026-01-06_15-43-03-839.csv
& 2026-01-06_15-44-18-512.csv
CH1 = HV x100
CH4 = LV x10
CH2 = Current

OLD DIODE 
NO load 
Minimum voltage must be like 345v (not mesured) 
2026-01-06_15-58-48-465.csv
2026-01-06_16-00-21-095.png 740ns ==> 740e-9*132e3=0.097 ~10% < 5%

350.9v no load 
Réparer le problème de masse Sonde CH4
2026-01-06_17-16-25-122.png
Calibration après réparation  0V 0A
2026-01-06_17-17-57-819

New output diode 
SB2100 (Vf multimeter is low like 0.34v...)
https://www.sangdest.com.cn/propdf/SB2100%20N0154%20REV.C.pdf
https://diotec.com/request/datasheet/sb220.pdf
351.2 11.35v
2026-01-06_17-43-30-844.png

377.5v
2026-01-06_17-45-21-093

401.9v
2026-01-06_17-46-24-611.txt

427.4v
2026-01-06_17-48-22-544

The Vin is the min (around 345V)
Vout rump up 11.35V meas 
2026-01-06_18-02-47-513
best measurement 11.34v
2026-01-06_18-10-59-970

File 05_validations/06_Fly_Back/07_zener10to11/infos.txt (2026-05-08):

Old Zener 10 V 
11.34v  425.2v
2026-01-08_17-24-24-203

New Zener 11 V 
12.08v/425.7v
2026-01-08_17-32-12-509

compare old vs new (ref = Zener 10 old)
2026-01-08_17-32-36-387

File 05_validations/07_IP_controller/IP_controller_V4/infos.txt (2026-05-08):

i used Test_ANALOG_SPEED_V2.ino
stm32 power by usb only 

SW
----------------------------
  Serial.print("dt(us)="); Serial.print(dt); Serial.print(" | ");
  Serial.print(a0); Serial.print(' ');
  Serial.print(a1); Serial.print(' ');
  float vout =0.03081*a1+ -0.09761; 
  Serial.print(vout); Serial.print(' ');
  Serial.print(a2); Serial.print(' ');
  Serial.print(a3); Serial.print(' ');
  Serial.print(a4); Serial.print(' ');
  Serial.print(a5); Serial.print(' ');
  Serial.print(a6); Serial.print(' ');
  Serial.println(a7);
------------------------------------------------------

RESULT Vcc of STM 32 (power by USB only) 3.323V
vout of insulation output voltage Amp = 2.891v
------------------------------------------------

dt(us)=17 | 409 3543 109.06 1425 2522 2303 278 2990 30
dt(us)=16 | 409 3543 109.06 1426 2521 2303 283 2991 28
dt(us)=16 | 415 3543 109.06 1428 2524 2304 293 2986 24
dt(us)=16 | 411 3544 109.09 1426 2524 2305 276 2986 27
dt(us)=17 | 409 3545 109.12 1429 2525 2305 278 2986 25
dt(us)=16 | 398 3545 109.12 1428 2523 2305 284 2988 26
dt(us)=17 | 403 3545 109.12 1427 2523 2304 278 2987 26
dt(us)=16 | 419 3547 109.19 1428 2525 2304 283 2984 23
dt(us)=17 | 422 3548 109.22 1430 2525 2306 286 2989 28
dt(us)=16 | 404 3545 109.12 1426 2523 2305 276 2986 25
dt(us)=16 | 402 3546 109.15 1428 2523 2305 280 2987 26
dt(us)=17 | 406 3548 109.22 1431 2525 2305 282 2986 25
dt(us)=16 | 412 3544 109.09 1429 2525 2307 287 2989 27
dt(us)=17 | 411 3544 109.09 1427 2523 2306 289 2989 28
dt(us)=17 | 408 3543 109.06 1427 2524 2307 285 2989 26
dt(us)=17 | 412 3545 109.12 1428 2523 2306 276 2987 25
dt(us)=17 | 408 3544 109.09 1428 2524 2306 286 2987 26
dt(us)=16 | 410 3545 109.12 1429 2523 2306 281 2987 27
Meas 
ADC1 = 3545
Theor 
ADC1 = 2**12*2.891/3.323= 3563 , 
error = 100*(3563-3545)/3545= 0.5% (ok) 
Vout(conversion thero) = 0.03081*3563+ -0.09761= 109.67
Measur= 109.12 V

Voutmax = 54V
1.5*Voutmax = 1.5*54= 81V
Limit of initialization = (95v middle of  (81+109)/2)

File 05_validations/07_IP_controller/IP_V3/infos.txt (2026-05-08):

IP_controller_V3
2026-01-25_11-22-16-052.png
i don't know why CH4 return to input instead of 3.3V 

IP_controller_V4
2026-01-25_11-38-00-218
ok 

vin 49.06
vout 5.95
SW freq min = 100khz
freq 99.86khz , vref = 8v
2026-01-25_12-27-46-948
estimation of Vout 
1: 5.95*(350/49.06)=42.44
2: 5.95*(380/49.06)=46.08V
3: 5.95*(400/49.06)=48.51v

IP_controller_V5
min freq 95.10
5.95=>6.116 
49.06=>49.03
6.116*(350/49.03)=43.64
6.116*(380/49.03)=47.40
6.116*(400/49.03)=49.92
2026-01-25_12-37-30-578

2026-01-25_12-40-36-874
CH3 = current of ID (0.007 ohm)

2026-01-25_12-42-25-298
CH4 = voltage of capacitor Cr 

------------------------------ 
CHANGE OF MOSFET 
VIN = 79.8V
2026-01-31_17-09-17-057.csv

VIN = 128V
2026-01-31_17-11-21-522.csv

VIN = 176V
2026-01-31_17-12-46-709.csv

Same input voltage
vout dc = 21.74V 
2026-01-31_17-47-18-597.png
no load 
CH4 = Vg of low side primary 
CH1 = Vds of low side primary 

2026-01-31_17-53-24-619.csv
CH4 = Vg of low side primary 
CH1 = Vds of low side primar
CH3= VinpA of driver (of same mos)

same and load ouput 51.9 ohm (same)
2026-01-31_17-56-09-532.csv

Same iput for CH4 and CH1
2026-01-31_18-03-10-391.png
delay in insulation probe = 5.84ns 

same input 
2026-01-31_20-09-34-892
CH4 = vout
CH1 = Vds of low side primar
no load
turn on

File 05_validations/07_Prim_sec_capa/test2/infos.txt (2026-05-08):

Rload 1.963 kohm  (ZC≈−j796 Ω at 100khz)
CH2  = 50 ohm 
2026-01-09_10-58-44-819
CH2 = 1Mohm 
2026-01-09_11-01-35-664.png
2.2MHz 50 Ohm in CH2
2026-01-09_11-03-25-740
10KHz 1MOhm in CH2
2026-01-09_11-04-59-458.png

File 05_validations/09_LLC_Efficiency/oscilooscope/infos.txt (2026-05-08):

check ZVS
CH1 = VDS LOW SIDE PRIM
CH4 = VGS LOW SIDE PRIM X10
2026-02-14_11-05-54-493
342.1V 40.97V

404.8V  48.5V
2026-02-14_11-08-58-560
100.3KHZ
2026-02-14_11-10-21-320.png

MEASUREMENT
45.56 V
380.1 V

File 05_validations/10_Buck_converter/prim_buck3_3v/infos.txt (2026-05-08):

No load external 
2026-02-15_11-34-18-004

20.5 load 3.3v
2026-02-15_11-49-18-257

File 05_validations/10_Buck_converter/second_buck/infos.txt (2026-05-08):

in 15.49v
out 11.96v

load 29.5V
2026-02-15_11-55-35-440

No load 
2026-02-15_11-56-52-881

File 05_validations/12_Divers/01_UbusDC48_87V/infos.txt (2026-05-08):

Udc = 48.87V
Ubootsrap 11.7V

Output no mos no capa open secondary 

2025-12-02_14-52-26-546
CH1 = Vout comp D_MOS1 - D_MOS2 
CH3 = Vgs low side Mos primary
CH4 = Vds low side Mos primary

2025-12-02_15-15-48-845.png
CH1 = Vout comp D_MOS1 - D_MOS2 
CH2 = Id low side Mos primary
CH3 = Voltage of capa Cr 

Add Secondary mosfets + 120uF x 7 + 1kohm Rload
2025-12-09_09-57-58-345.png
CH3 = Vds of the primary low side 
CH4 = Vds of the secondary same side 
vmeas_out/inp (DC) = 8.63v 49.04v
49.04/4/sqrt(2)=8.669V

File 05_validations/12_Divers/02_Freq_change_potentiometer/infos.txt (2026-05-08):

Udc = 49.06V
Ubat 11.85V

Juste FOR YOUR INFO 
59.95	11.26
68.05	9.4

2025-12-09_14-47-45-457.png ==> Vout = 11.26V 

CH1 = Vout (x100 isolated)
CH2 = Vds secondary low side 
CH3 = V_Cr
CH4 = Vds Primary Low side x 10

2025-12-09_14-53-35-369 ==> 0v 0v 0v 0v

UDC = 97.2v UOUT = 16.11V
2025-12-12_11-18-16-855.png
2025-12-12_11-22-38-405.png

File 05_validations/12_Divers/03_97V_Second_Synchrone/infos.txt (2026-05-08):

UDC = 97.1V

UOUT = 12.58v
12Vsec = 11.40v
2025-12-12_14-52-55-994 

Rload = 40 ohm instead of 1kohm 
2025-12-12_15-38-31-658

Low freq (heigh output) 
2025-12-12_15-45-11-354.png

CH1 = VDS LOW SEC 
CH2 = VGS H SEC 
CH4 = VGS L SEC
2025-12-12_15-50-55-668.txt

2025-12-12_17-33-55-660.png
Adding R_cs = 220 ohm for both Secondaries mos controller 
CH1 = VDS LOW SEC 
CH2 = VGoud_Cs (Pin 6 of the ic)

48V UDC
/!\/!\/!\/!\
I maked i very big mistake 
in all this folde 
VDS = VDG actually 
I found that i measure VDG why : beachase before adding ic controller i have S = G (short circuit) 
Since 2025-12-12_18-00-00-677.png i correct CH1 = Real VDS

2025-12-12_18-12-36-329.png
CH1 = VDS LOW SEC 
CH2 = VGS H SEC 
CH4 = VGS L SEC

Open the jumpers Gates are floting 
2025-12-12_18-16-57-016.png

RCS = 1kom no impact 
1k*100u = 100mV
2025-12-12_18-22-07-801.png

return to RC = 0 
some time the Ton is normal but some time is juste 1us 
see
2025-12-12_18-35-36-396.png
see 2025-12-12_18-36-56-210.png (not repatable)

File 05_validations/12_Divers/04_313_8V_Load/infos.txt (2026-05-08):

UDC = 313.8
RGs = 1.1ohm 
UOUT open = 38V (around) 128kHz 
CH1 = VDC L SECON
CH4 = VGS L SECON (befor 1.1 ohm, driver output) 
CH2 = VGS H SECON

No load 
2025-12-12_21-04-59-234.png
Load 52 ohm 
2025-12-12_21-07-09-791.png
Load 35.8 ohm 
2025-12-12_21-08-47-672
Loaf 22.8 ohm
2025-12-12_21-09-48-585.png

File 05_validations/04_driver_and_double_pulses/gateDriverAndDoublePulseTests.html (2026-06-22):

# Gate driver and double pulse tests

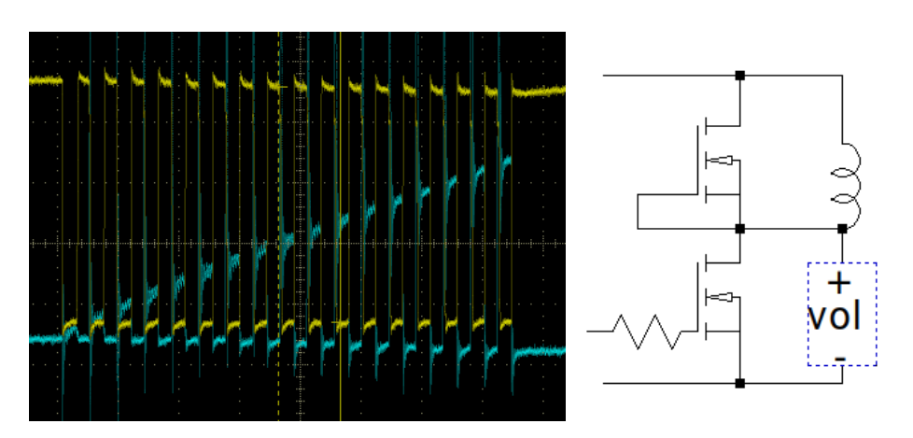
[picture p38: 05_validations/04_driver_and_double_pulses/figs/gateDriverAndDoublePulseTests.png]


## Table of contents¶

- Primary driver
  - Driver HW dead time
  - Bootstrap circuit
- Double pulse test
  - Setup
  - Example of the pre-processing
  - Rg impact
- Gate current
- Secondary driver
- Annexes
  - Carat of the big Lm
  - Quick prototyping of rogowski coil
  - Double pulse code STM32f103
  - Miller effect: Simple explanation

## Primary driver¶

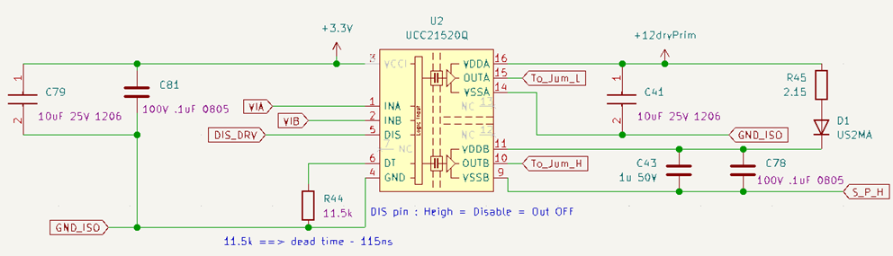
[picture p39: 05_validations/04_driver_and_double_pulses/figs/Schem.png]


Figure 1 Reminder of the primary gate driver sub-schematic: Final version

### Driver HW dead time¶

Let's check the accuracy of the programmed (HW) dead time of the used driver (UCC21520Q)

No SW dead time was programmed, the dead time is managed ONLY by thr RT = 11.5kΩ

Oscilloscope:

- CH1 : INA
- CH2 : INB
- CH3 : OUTA
- CH4 : OUTB

Driver:
ucc21520Q

Programmed dead time
RT = 11.5k, so dead time = 115ns

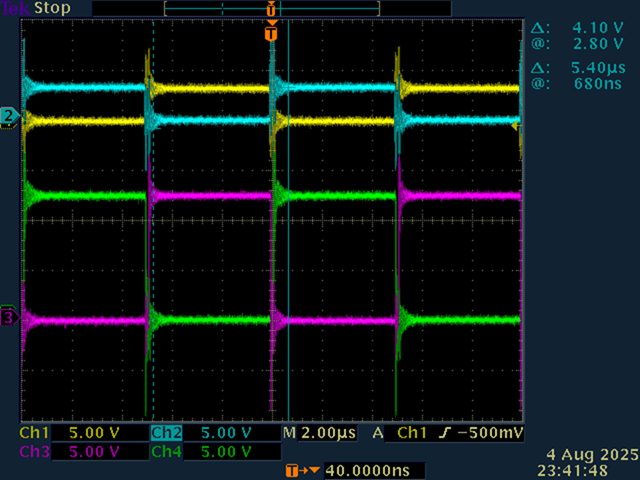
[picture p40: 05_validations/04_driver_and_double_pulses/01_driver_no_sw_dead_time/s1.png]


Figure 2 Zoom out to see 2 periods, 100khz

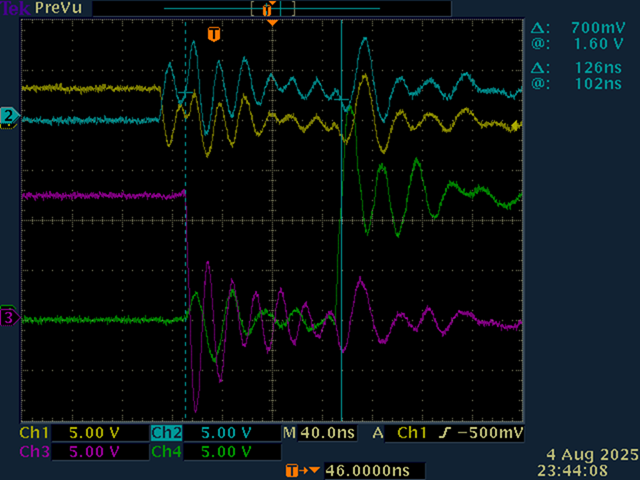
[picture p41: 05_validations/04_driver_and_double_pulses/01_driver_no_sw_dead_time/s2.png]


Figure 3 Zoom in around the dead time: DT=126ns

No description has been provided for this image

Figure 4 Zoom out to see 2 periods, 100khz

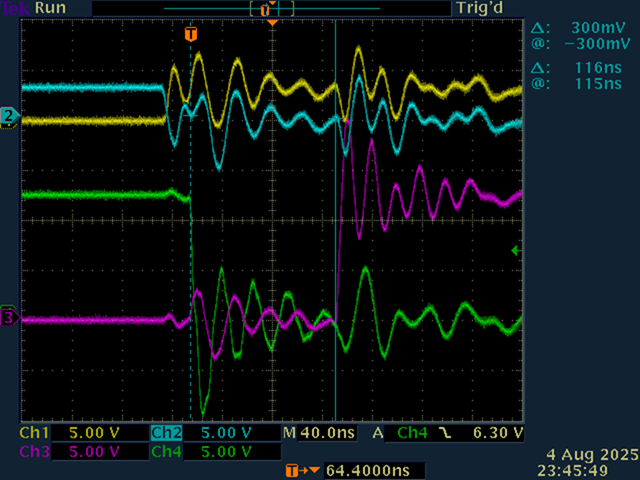
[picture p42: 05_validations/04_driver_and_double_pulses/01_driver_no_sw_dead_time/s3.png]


Figure 5 Zoom in around the dead time: DT=116ns

$ \begin{aligned} \mathrm{DT}_{Prog} &= 115 \; \;\textrm{(ns)} \\ \mathrm{DT}_{Meas} &= 116 \; \;\textrm{(ns)} \\ \mathrm{Error} &= 100 \cdot \frac{ \mathrm{DT}_{Meas} - \mathrm{DT}_{Prog} }{ \mathrm{DT}_{Prog} } = 100 \cdot \frac{ 116 - 115 }{ 115 } &= 0.87 \; \;\textrm{(\%)} \end{aligned} $

So the mesured dead time is very accurate

### Bootstrap circuit¶

Lest's check the bootstrap circuit (DRC)

SINGLE pulse

In this test, the low-side MOSFET is driven by a single long pulse.

Peak current estimation :

$ \begin{aligned} \mathrm{V12} &= 12 \; \;\textrm{(V)} \\ \mathrm{Vd} &= 0.700 \; \;\textrm{(V)} \\ \mathrm{Rboot} &= 2.150 \; \\ \mathrm{Iboot} &= \frac{ \mathrm{V12} - \mathrm{Vd} }{ \mathrm{Rboot} } = \frac{ 12 - 0.700 }{ 2.150 } &= 5.256 \end{aligned} $

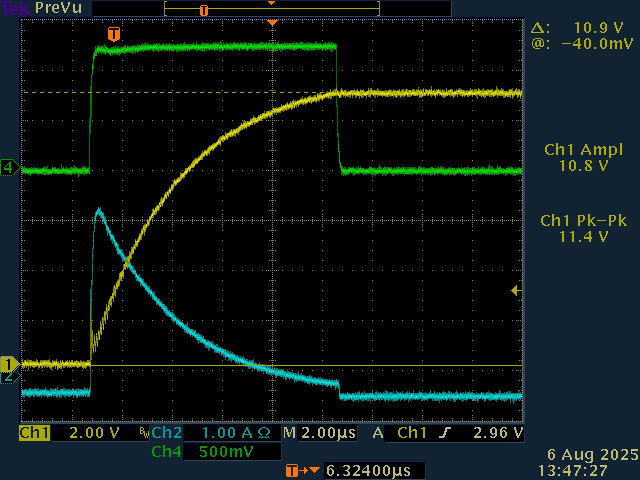
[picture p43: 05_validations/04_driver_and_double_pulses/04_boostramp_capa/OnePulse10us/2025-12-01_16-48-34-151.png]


Figure 6 Bootstrap circuit measurement with 10us pulse width

Oscilloscope:

- CH1 : bootstrap capacitor voltage
- CH2 : bootstrap diode current
- CH4 : Vgs low side MOSFET

Peak current measurement :

$ I_{bootMeasure} $ ~ 3.8 Apeak

The measured peak current is lower than the estimated value because the estimate was based on the assumption that the only resistance in the path was the 2.15-Ωresistor, which represents a pessimistic (worst-case) assumption.

Below is a fast/simplified reproduction of this test in simulation

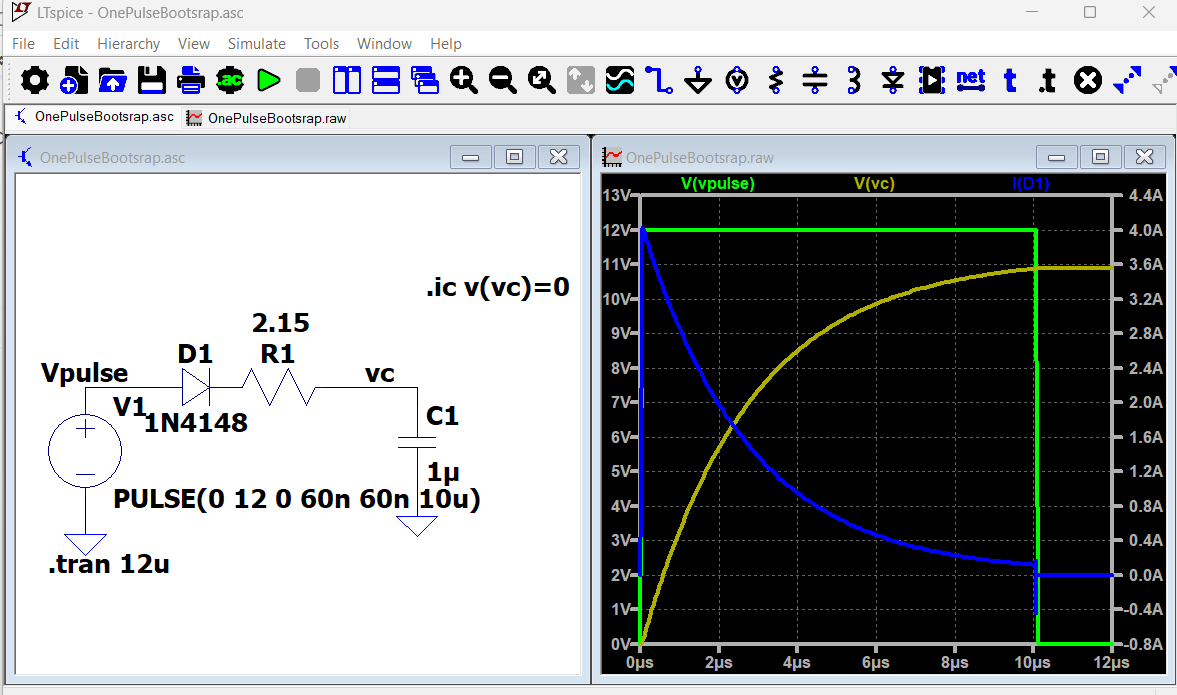
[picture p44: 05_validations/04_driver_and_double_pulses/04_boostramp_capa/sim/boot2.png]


Figure 7 Quick simulation of the bootstrap circuit with 10us pulse width

PWM mode

In this test, the low-side MOSFET is driven by a pulse train with frequency of 100kHz (more realistic).

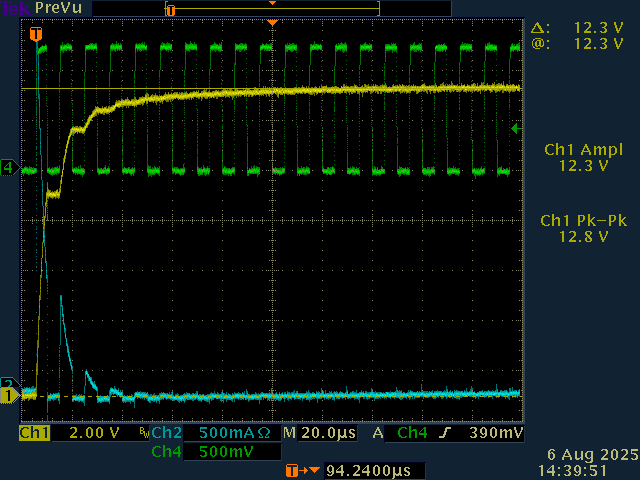
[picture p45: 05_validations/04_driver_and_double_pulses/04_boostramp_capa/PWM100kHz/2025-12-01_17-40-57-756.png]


Figure 8 Bootstrap circuit measurement with PWM 100kHz 50% duty cycle

Below is a fast/simplified reproduction of this test in simulation

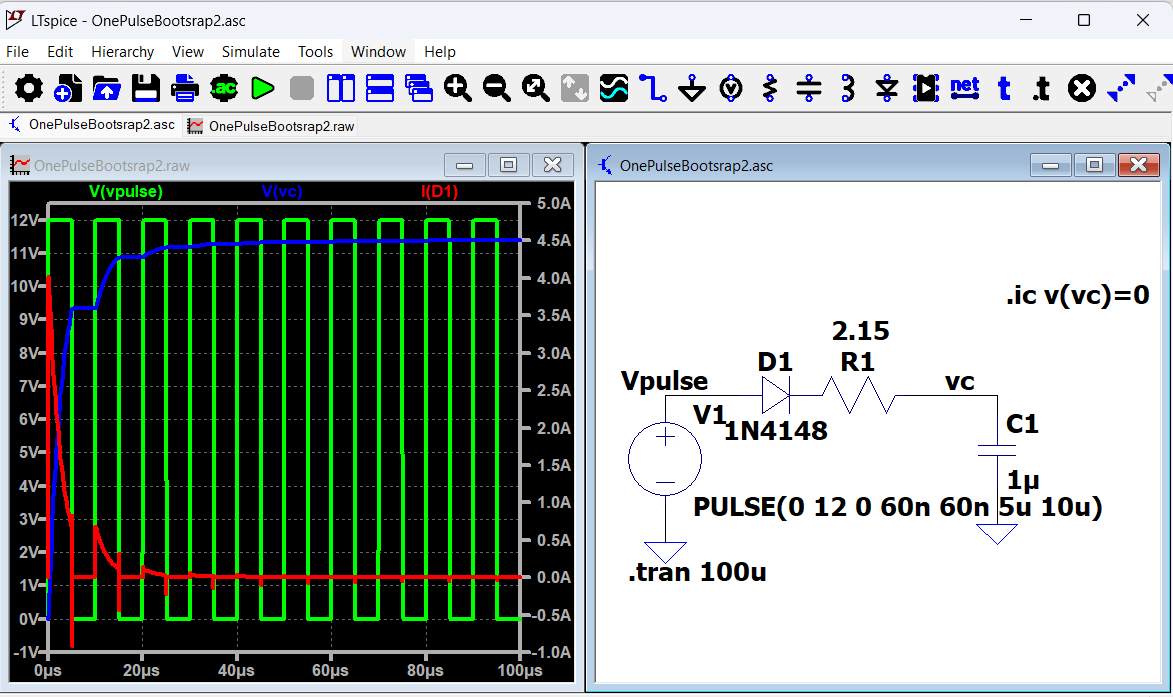
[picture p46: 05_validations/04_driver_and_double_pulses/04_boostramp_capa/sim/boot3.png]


Figure 9 Quick simulation of the bootstrap circuit 100kHz 50% duty cycle

Estimation of the charge time of the bootstrap capacitor:

$ \begin{aligned} C &= 1 \; \;\textrm{(µs)} \\ R &= 2.150 \; \;\textrm{(ohm)} \\ \mathrm{To} &= R \cdot C = 2.150 \cdot 1 &= 2.150 \; \;\textrm{(µs)} \end{aligned} $

3 corresponds to the 99% level, and 2 represents the 50% duty cycle.

$ \begin{aligned} \mathrm{time} &= \mathrm{To} \cdot 5 \cdot 2 = 2.150 \cdot 5 \cdot 2 &= 21.500 \; \;\textrm{(µs)} \end{aligned} $

So minimum time to charge the capacitor is 22µs or 3 periodes of 100khz

## Double pulse test¶

### Setup¶

We used the primary side of the DC-DC (without ferrite elements) to make the double pulse test.

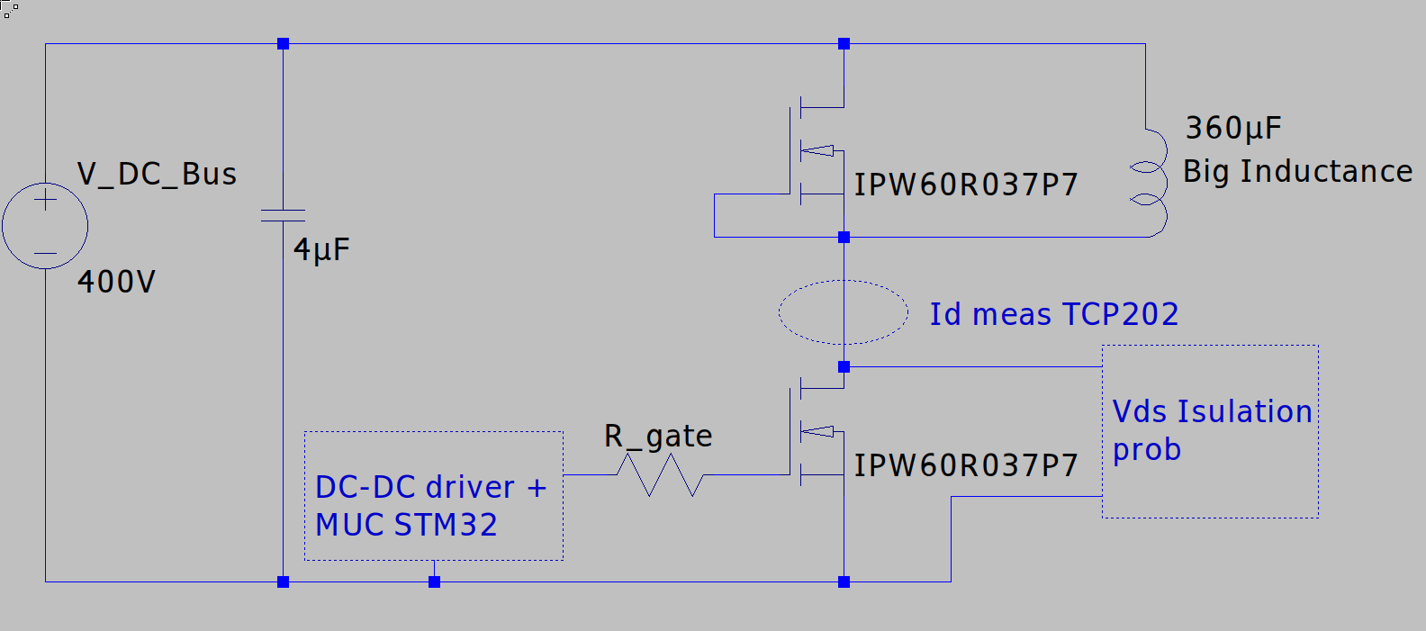
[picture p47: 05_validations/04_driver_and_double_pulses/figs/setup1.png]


Figure 10 Double pulse setup

No description has been provided for this image

Figure 11 Double pulse setup (with the big inductance 360µH, 16 turns)

### Example of the pre-processing¶

In this section an example of pre-processing measured signal to calculate the Eon, and Eoff energy

- V_bus = 366.5V
- V_lv = 12.34v
- R_gate_ext = 10Ω

Step 1: Load the csv files

No description has been provided for this image

Figure 12 Quick simulation of the bootstrap circuit with 10us pulse width

No description has been provided for this image

Step 2 : Pre-processing the current

The used current prob has a heigh pass filter effect, so below a pre-processing to remove this effect.

No description has been provided for this image

Step 3: Detection of the rise/fall instants

No description has been provided for this image

Step 4: zoom around the switching instants

No description has been provided for this image

Step 5: Estimation of the Coss capacitor

No description has been provided for this image

Formulas to calculate the mosfet capacitors:

Time related capacitance

$i = C \frac{dv}{dt}$

$C_o(tr)= \frac{\int i \cdot dt}{\int dv} = \frac{Q}{\Delta V}$

Energy-related capacitance

$E = \int v \cdot i \cdot dt$

$C_{o(er)} = \frac{2E}{\Delta V^2}$

dv is measured between min_v + 50V and max_v - 50V

No description has been provided for this image

Why the estimation of Co-Energy is good at low corrent, and bad in heigh current: $$E_{total} = E_{oss} + E_{switching\_loss}$$

In low current loss energy is low so almost the all measured energy is the stored energy in the mosfet capacitor, but in heigh current a part of energy is converted to heat.

To reproduce this phynomina, I propose the simple simulation below:

No description has been provided for this image

Figure 13 Simple simulation of the turning off instant of SPA11N60C3

Lest's calculating the sw-enrgy and the coresponding capacitor using pre-processing of the raw data using python

Text(0.5, 1.0, 'Switching power = Id * Vds (W)')

No description has been provided for this image

No description has been provided for this image

So , we can see the same behaviour our measurement

For information dv/dt:

Shown below are the dv/dt measured during turn-off and the corresponding current as a function of isolation capacitance, for the case where an isolated power supply is used to power the high-side driver.

No description has been provided for this image

In IPW60R037P7 datasheet (https://www.infineon.com/assets/row/public/documents/24/49/infineon-ipw60r037p7-ds-en.pdf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), we can cound :

- Rise time (tr) = 21ns
- @ VDD=400V,VGS=13V,ID=29.5A, RG=3.3Ω

So $dv/dt = 19V/ns$

The "dv/dt meas" has a maximum,this explain by $$\frac{dv}{dt}_{max} = \frac{V_{gsPlateau} - V_{EE}}{R_{g_tot} \cdot C_{gd}}$$

Since driver is powered by 12V/0V (no $V_{EE}$), so: $$\frac{dv}{dt}_{max} = \frac{V_{gsPlateau} }{R_{g_tot} \cdot C_{gd}}$$

where

$C_{gd}$ : Gate-Drain capa, $C_{rss}$ in datasheet

No description has been provided for this image

Figure 14 IPW60R037P7 datasheet: Crss = 22pF at 366V

Let's calculate the theorical dv/dt_max:

$ \begin{aligned} R_{gMosfet} &= 0.860 \; \;\textrm{(Ω , see IPW60R037P7 datasheet)} \\ R_{driver} &= 5 \; \;\textrm{(Ω , see UCC21520Q datasheet)} \\ R_{ext} &= 10 \; \;\textrm{(Ω , in this example)} \\ R_{gTot} &= R_{gMosfet} + R_{driver} + R_{ext} = 0.860 + 5 + 10 &= 15.860 \; \;\textrm{(Ω)} \end{aligned} $

$ \begin{aligned} V_{gsPlateau} &= 5.200 \; \;\textrm{(V , see IPW60R037P7 datasheet)} \\ C_{g} &= 22 \; \;\textrm{(pF , see fig above)} \\ \mathrm{dvdt} &= \frac{ V_{gsPlateau} }{ R_{gTot} \cdot C_{g} \cdot 1 \times 10 ^ {-3} } = \frac{ 5.200 }{ 15.860 \cdot 22 \cdot 1 \times 10 ^ {-3} } &= 14.903 \; \;\textrm{(V/ns)} \end{aligned} $

The maximum dv/dt measured is around 13 - 14 V/ns, so our theorical estimation is very close

### Rg impact¶

In this section, we will change gate resistor, and check the impact in the loss energy.

We calculating the Eon just for information, since we are in ZVS, Eon is very low, and the calculated Eon is compatible with no ZVS function.

In the PCB we mount 3 resistors in parallel for Rg, 3 Ω , 5 Ω and 10 Ω with a jumper, so it will be easy to change Rg using this value, or any combinason of parallel configuration like 3 Ω // 5 Ω = 1.875 Ω and 3 Ω // 10 Ω =2.30 Ω (see the photo below)

Just for information, we broked the mosfet during this test @400V, so we recommande to no make SW-ON.

No description has been provided for this image

Figure 15 The Jumper used to select Rg

No description has been provided for this image

Figure 16 Jumper in the PCB with the 3 resostors (3D)

We followed the same steps as shown in the example above to calculate the Eon/Eoff of each Rg configuration

No description has been provided for this image

Rg = 3 Ω is a good compromise between reducing the switching energy and avoiding oscillation, we will conserve this value for this project

## Gate current¶

n this test, we measured the gate current using TCP202, so a small loop wire is added to the current path to insert the current probe (inductance)

The test was done in low voltage condition:

- Vin = 48.03V
- Vout = 8.03V
- Freq = 150kHz (Max freq of the DC-DC)

This test is done with the old primary mosfet (before updating the BOM)

No description has been provided for this image

Figure 17 Primary-Low side gate current/voltage

Pre-Processing of the oscilloscope raw data

No description has been provided for this image

We canestimate the $R_{gTot}$
Let's consider that so inductance is present the the gate loop.

$ \begin{aligned} V_{DRV} &= 12 \; \\ V_{gsTpeak} &= 6 \; \\ I_{gTpeak} &= 0.730 \; \\ R_{gTot} &= \frac{ V_{DRV} - V_{gsTpeak} }{ I_{gTpeak} } = \frac{ 12 - 6 }{ 0.730 } &= 8.219 \; \;\textrm{(ohm)} \end{aligned} $

Theorical value :

$ \begin{aligned} R_{gMosfet} &= 0.860 \; \;\textrm{(Ω , see IPW60R037P7 datasheet)} \\ R_{driver} &= 5 \; \;\textrm{(Ω , see UCC21520Q datasheet)} \\ R_{ext} &= 3 \; \;\textrm{(Ω , design)} \\ R_{tot} &= R_{gMosfet} + R_{driver} + R_{ext} = 0.860 + 5 + 3 &= 8.860 \; \;\textrm{(Ω)} \end{aligned} $

The results are very close

MOSFET: Miller plateau

No description has been provided for this image

The Miller plateau is not very pronounced because the SW-ON is in ZVS mode and at low voltage.

## Secondary driver¶

Reminder of the secondary-side synchronous rectifier driver

the master ic : NCP43080DDR2G

No description has been provided for this image

Figure 18 The driver NCP43080DDR2G

No description has been provided for this image

Figure 19 Jumper to shose Rg from 0, 1, 3 ohm

The controller presents a limitation, its conduction time depends heavily on the load; see the test below.

Test conditions:

- Vin = 393.5 v
- Vout = 48.11 v

Oscilloscope:

- CH1 : Vds low side primary x 100
- CH2 : Vgs low side secondary: driver output
- CH4 : Vds low side secondary x 10

No description has been provided for this image

Figure 20 no load

No description has been provided for this image

Figure 21 load1 52.1 ohm

No description has been provided for this image

Figure 22 load2 36 ohm

No description has been provided for this image

Figure 23 load3 3 24.5 ohm

No description has been provided for this image

Figure 24 load4 12.8 ohm

No description has been provided for this image

Figure 25 load5 9.2 ohm

Grouping of all test data :

No description has been provided for this image

Figure 26 PreProcessing of the test results

## Annexes¶

### Carat of the big Lm¶

No description has been provided for this image

Figure 27 Current

No description has been provided for this image

Figure 28 Voltage

We used the same double-pulse setup to characterize the large 16-turn inductor.

See the oscilloscope above (CH1 is and isolated x 100 prob)

$ \begin{aligned} N &= 16 \; \;\textrm{(turns)} \\ \Delta_{I} &= 1.820 \; \;\textrm{(A)} \\ \Delta_{t} &= 7.360 \; \;\textrm{(µs)} \\ V_{L} &= 928 \cdot 100 \cdot 1 \times 10 ^ {-3} &= 92.800 \; \;\textrm{(V)} \end{aligned} $

Since $ V_L = L \frac{di}{dt}$

$ \begin{aligned} L &= V_{L} \cdot \left( \frac{ \Delta_{t} }{ \Delta_{I} } \right) = 92.800 \cdot \left( \frac{ 7.360 }{ 1.820 } \right) &= 375.279 \; \;\textrm{(µH)} \\ \mathrm{AL} &= 1 \times 10 ^ {3} \cdot \frac{ L }{ \left( N \right) ^{ 2 } } = 1 \times 10 ^ {3} \cdot \frac{ 375.279 }{ \left( 16 \right) ^{ 2 } } &= 1465.934 \; \;\textrm{(nH/turn2)} \end{aligned} $

### Quick prototyping of rogowski coil¶

During this project, we experimented with several methods to produce a prototype of a Rogowski coil, The idea is to prototype a very simple Rogowski coil and perform the integration via signal preprocessing.

the produced signal is:
$e = k .di/dt$

So a preprocessing integral is necessary and an empirical estimation of the coed k

Below some image of the prototyped coils:

No description has been provided for this image

Figure 29

No description has been provided for this image

Figure 30

No description has been provided for this image

Figure 31

No description has been provided for this image

Figure 32

No description has been provided for this image

Figure 33

No description has been provided for this image

Figure 34

No description has been provided for this image

Figure 35

No description has been provided for this image

Figure 36

No description has been provided for this image

Figure 37

No description has been provided for this image

Figure 38

No description has been provided for this image

Figure 39

No description has been provided for this image

Figure 40

The proprocessing

No description has been provided for this image

Figure 41 Example of measurement

- CH3 is TCP202 360µH current
- CH4 Rogowski coil voltage (therminal 50ohm)

No description has been provided for this image

No description has been provided for this image

Preprocessed rogowski signal is very good to detect fast change of the current but bad in low frequency area

### Double pulse code STM32f103¶

Simple double pulse code

#include "stm32f1xx.h"

#define CPU_FREQ 72000000UL
#define PA9_SET  (1u << 9)
#define PA9_RST  (1u << (9 + 16))
#define PA9_BIT  (1u << 9)

static inline void dwt_start(void) {
  CoreDebug->DEMCR |= CoreDebug_DEMCR_TRCENA_Msk;
  DWT->CYCCNT = 0;
  DWT->CTRL |= DWT_CTRL_CYCCNTENA_Msk;
}

void setup(void) {
  // Enable GPIOA clock
  RCC->APB2ENR |= RCC_APB2ENR_IOPAEN;

  // PA9 = General purpose push‑pull output, 50 MHz (CRH bits [7:4])
  GPIOA->CRH &= ~(0xFu << 4);
  GPIOA->CRH |=  (0x3u << 4);   // MODE9=11 (50MHz), CNF9=00 (GP PP)

  // Ensure USART1 doesn't grab PA9 (we don't enable it)
  RCC->APB2ENR &= ~RCC_APB2ENR_USART1EN;

  dwt_start();

  // Quick self-check: force LOW and verify ODR reflects it
  GPIOA->BSRR = PA9_RST;
  if (GPIOA->ODR & PA9_BIT) { for (;;){ /* trap if config failed */ } }
}

void loop(void) {
  uint32_t ton1  = 2; // us
  uint32_t toff1 = 1; // us
  uint32_t ton2  = 1; // us
  uint32_t toff2 = 1; // us

  GPIOA->BSRR = PA9_SET; 
  delayMicroseconds(ton1); 

  GPIOA->BSRR = PA9_RST; 
  delayMicroseconds(toff1);
   
  GPIOA->BSRR = PA9_SET; 
  delayMicroseconds(ton2);

  GPIOA->BSRR = PA9_RST;
  delayMicroseconds(toff2);
}

Train of double pulse

#include "stm32f1xx.h"

// --- PA9 macros ---
#define PA9_SET   (1u << 9)
#define PA9_RST   (1u << (9 + 16))

// --- PB14 macros ---
#define PB14_SET  (1u << 14)
#define PB14_RST  (1u << (14 + 16))

#define _Ena_drv PB10
#define _Dis_drv PB12

void setup() {
// Force PB12 HIGH in output data register BEFORE pinMode changes the mode
// digitalWrite(_Dis_drv, HIGH);     // preload ODR = 1 (float high in open-drain mode)
digitalWrite(_Dis_drv, LOW); 
pinMode(_Dis_drv, OUTPUT_OPEN_DRAIN);
digitalWrite(_Dis_drv, LOW); // redundancy
digitalWrite( _Ena_drv, HIGH); 
pinMode(_Dis_drv, OUTPUT);
digitalWrite( _Ena_drv, HIGH); 

/////// PA9 & PB14 as Fast output ///////////
  // Enable GPIOA + GPIOB clocks
  RCC->APB2ENR |= RCC_APB2ENR_IOPAEN | RCC_APB2ENR_IOPBEN;

  // --- PA9 = 50 MHz push-pull output ---
  GPIOA->CRH &= ~(0xF << 4);   // clear config bits
  GPIOA->CRH |=  (0x3 << 4);   // MODE9=11 (50MHz), CNF9=00
  GPIOA->BSRR = PA9_RST;       // start LOW

  // --- PB14 = 50 MHz push-pull output ---
  GPIOB->CRH &= ~(0xF << 24);  // PB14 config bits
  GPIOB->CRH |=  (0x3 << 24);  // MODE14=11, CNF14=00
  GPIOB->BSRR = PB14_RST;      // start LOW

}

__attribute__((always_inline)) 
static inline void delayNs(uint32_t tns)
{
    /*
    target => oscilo
    6000ns => 5986ns 
    1000ns => 985.3ns
    */

    uint32_t iterations = (tns * 72) / (6.08*1000);

    for (uint32_t i = 0; i < iterations; i++) {
        __asm__ __volatile__("nop" ::: "memory");
    }
}

void loop() {

//////////// ENABLE DRIVER 
delayMicroseconds(10); 
digitalWrite(_Dis_drv, HIGH); // redundancy
digitalWrite( _Ena_drv, LOW); 
delayMicroseconds(10); 
digitalWrite( _Ena_drv, HIGH); 

/////////// double pulse waveform on / off / on /off

  uint32_t ton  = 1000; // ns
  uint32_t toff = 800; // ns
  uint32_t N  = 17; // n of pulses

  for (int i = 0; i<N; i++){
  GPIOA->BSRR = PA9_SET; 
  delayNs(ton);
  GPIOA->BSRR = PA9_RST; 
  delayNs(toff);
  }

  while(1); 

}

### Miller effect: Simple explanation¶

#### Miller effect: Simple modelization¶

In this part, we propose a simple explanation of miller effect in the mosfet

From the IPW60R037P7 datasheet (https://www.infineon.com/assets/row/public/documents/24/49/infineon-ipw60r037p7-ds-en.pdf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), we can cound : we can found

$ \begin{aligned} \mathrm{Qgs} &= 27 \; \;\textrm{(nC)} \\ \mathrm{Qgd} &= 37 \; \;\textrm{(nC)} \\ \mathrm{VGS} &= 10 \; \;\textrm{(v)} \\ \mathrm{VDD} &= 400 \; \;\textrm{(v)} \\ \mathrm{CO}_{en} &= 1599 \; \;\textrm{(pF (time related))} \\ V_{gsPlateau} &= 5.200 \; \;\textrm{(V)} \end{aligned} $

Calculating the average capacitors (actual capacitors depend on the voltage, but we will take this hypothesis)

$ \begin{aligned} \mathrm{Cgd} &= \frac{ \mathrm{Qgd} }{ \mathrm{VDD} - \mathrm{VGS} } = \frac{ 37 }{ 400 - 10 } &= 0.095 \; \;\textrm{(nF)} \\ \mathrm{Cgs} &= \frac{ \mathrm{Qgs} }{ V_{gsPlateau} } = \frac{ 27 }{ 5.200 } &= 5.192 \; \;\textrm{(nF)} \end{aligned} $

- In the below simulation, we modulate the mosfet with ideal switch and capacitors
- We use a simple capacitor circuit ot make integral of the gate current
- For Cgs, we will use a value of 8 nF to compensate for the non-linearity of this capacitor.

No description has been provided for this image

Figure 42 Simple LTSPice simulation

No description has been provided for this image

Figure 43 Simple LTSPice simulation: Time result

Result:

No description has been provided for this image

Figure 44 Simple LTSPice simulation: Result

No description has been provided for this image

Figure 45 Datasheet

Using the very simple MOSFET model, we have already identified the overall signature of the Miller plateau:

- $\Delta_Q = 65-25 = 40nC$ (datasheet)
- $\Delta_Q = 34nC$ (Simulation)

Why an oscillation? Because the model is very simple: no inductance loop, no resistance, constant capacitor, ideal diode...

#### Miller effect cross-conduction problem¶

One of the challenges associated with the Miller effect concerns the turn-off phase:

To illustrate this problem, shown below is a simple simulation model using a half-bridge and an LC branch to achieve ZVS.

- The gate resistance is identical for both SW-on / SW-off.
- It can be observed that the drain current (in purple) make a 200A spike (caused by a short circuit between the high/low side MOSFETS).

No description has been provided for this image

Figure 46 Simple LTSPice simulation: NO ROFF branch, dead time =200ns

By adding a resistor R_off, the discharge time is fast and no short circuit occurs

No description has been provided for this image

Figure 47 Simple LTSPice simulation: with ROFF branch, dead time =200ns

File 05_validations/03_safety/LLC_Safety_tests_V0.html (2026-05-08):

# LLC converter - Safety tests¶

No description has been provided for this image

## Table of contents¶

- Capacitor discharging
  - Setup
  - Test of normal operation
  - No switching, only flyback and fans
  - Only flyback no fans
  - Passive discharge, only discharge resistors
- Insulation test
  - Setup
  - Result

## Capacitor discharging¶

### Setup¶

The setup is relatively simple: a power supply (400 V) is connected to the HV connector, and a relay is used to open the circuit and measure the discharge voltage.

No description has been provided for this image

Figure 1: Capacitor discharge setup

In this DC‑DC converter, the flyback UVLO resistor is removed, so the flyback remains active down to 30 V and therefore acts as an active discharge path.

For safety, the DC input voltage measurement divider is designed to discharge the input even if the flyback fails.

### Test of normal operation¶

In this test, the Rload is 27 $\ohm$ (around 85W)

No description has been provided for this image

Figure 2: Capacitor discharge setup

The $\Delta t$ to discharge the capacitor from 400V to less than 60v (56v) is 23.7ms.

### No switching, only flyback and fans¶

For this test, the microcontroller was removed, meaning no switching occurs. Only the auxiliary flyback is powered at 400 V, and its output primarily drives the two fans, each rated at 12 V, 0.13 A, and 1.6 W

No description has been provided for this image

Figure 3: Capacitor discharge setup

The $\Delta t$ to discharge the capacitor from 400V to less than 60v (56v) is 84.8ms.

### Only flyback no fans¶

In this test, the microcontroller was removed, eliminating any switching activity. Only the auxiliary flyback is powered at 400 V, and with no fans connected, all of the flyback’s input power is dissipated.

No description has been provided for this image

Figure 4: Capacitor discharge setup

The $\Delta t$ to discharge the capacitor from 400V to 60v is 396ms.

### Passive discharge, only discharge resistors¶

Because the auxiliary flyback cannot be disabled by design, this final case will be evaluated only through simulation. The capacitor and resistor values are selected to model the worst‑case scenario.

No description has been provided for this image

Figure 5: Capacitor discharge setup

In this simulation, we considered the worst case for all components:

- DC-Link capacitor: 10% according to the datashet.
- Resonant capacitor: 5% according to the datashet.
- EMI filter differential mode capacitor: 10% according to the datashet.
- Discharge resistor (the same resistor used in the measurement divider): 1%, while the datasheet specifies only 0.1%

The discharge time between 400 V and 60 V is 3.6 s, fully satisfying the 5‑second requirement.

Even with 600V, the discharge time is 4.4s => satisfying the 5‑second requirement (see below)

No description has been provided for this image

Figure 6: Capacitor discharge setup

the below table group all result.
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

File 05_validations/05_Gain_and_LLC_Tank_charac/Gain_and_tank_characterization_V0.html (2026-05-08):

# Gain, Lr and Lm characterization¶

No description has been provided for this image

## Table of contents¶

- Single pulse setup
  - Setup
  - Lm Without air gap
  - Lm With Air gap
  - Lr Without air gap
  - Lr with air gap
  - The final result of Lr, Lm
- Resonant-circuit-based measurement method
  - Setup
  - Current measurement methodes
  - Lr+Lm
  - Lr
  - Lm
  - Why is it difficult to fit the LRC curve?
- Small-signal characterization
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

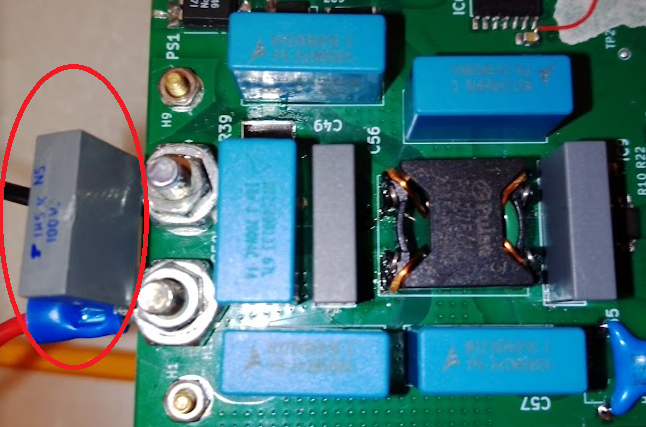
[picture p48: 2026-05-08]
05_validations/02_emc/01_Conducted_Emissions_Test/test4/figs/1u5.png

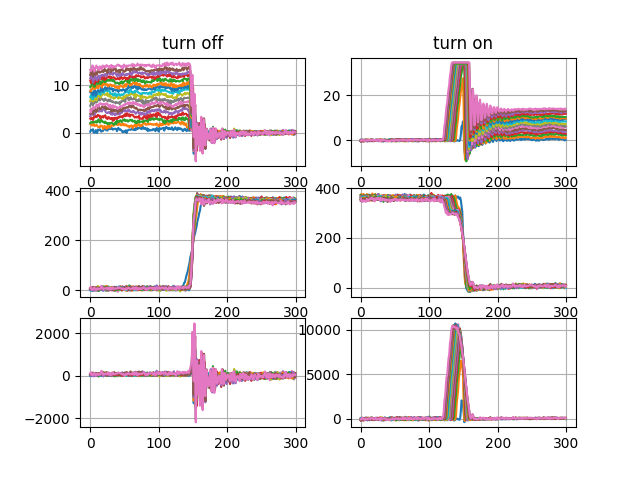
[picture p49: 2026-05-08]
05_validations/04_driver_and_double_pulses/02_double_pulse/366.5V_V3/figs/3__5=1.87ohm.png

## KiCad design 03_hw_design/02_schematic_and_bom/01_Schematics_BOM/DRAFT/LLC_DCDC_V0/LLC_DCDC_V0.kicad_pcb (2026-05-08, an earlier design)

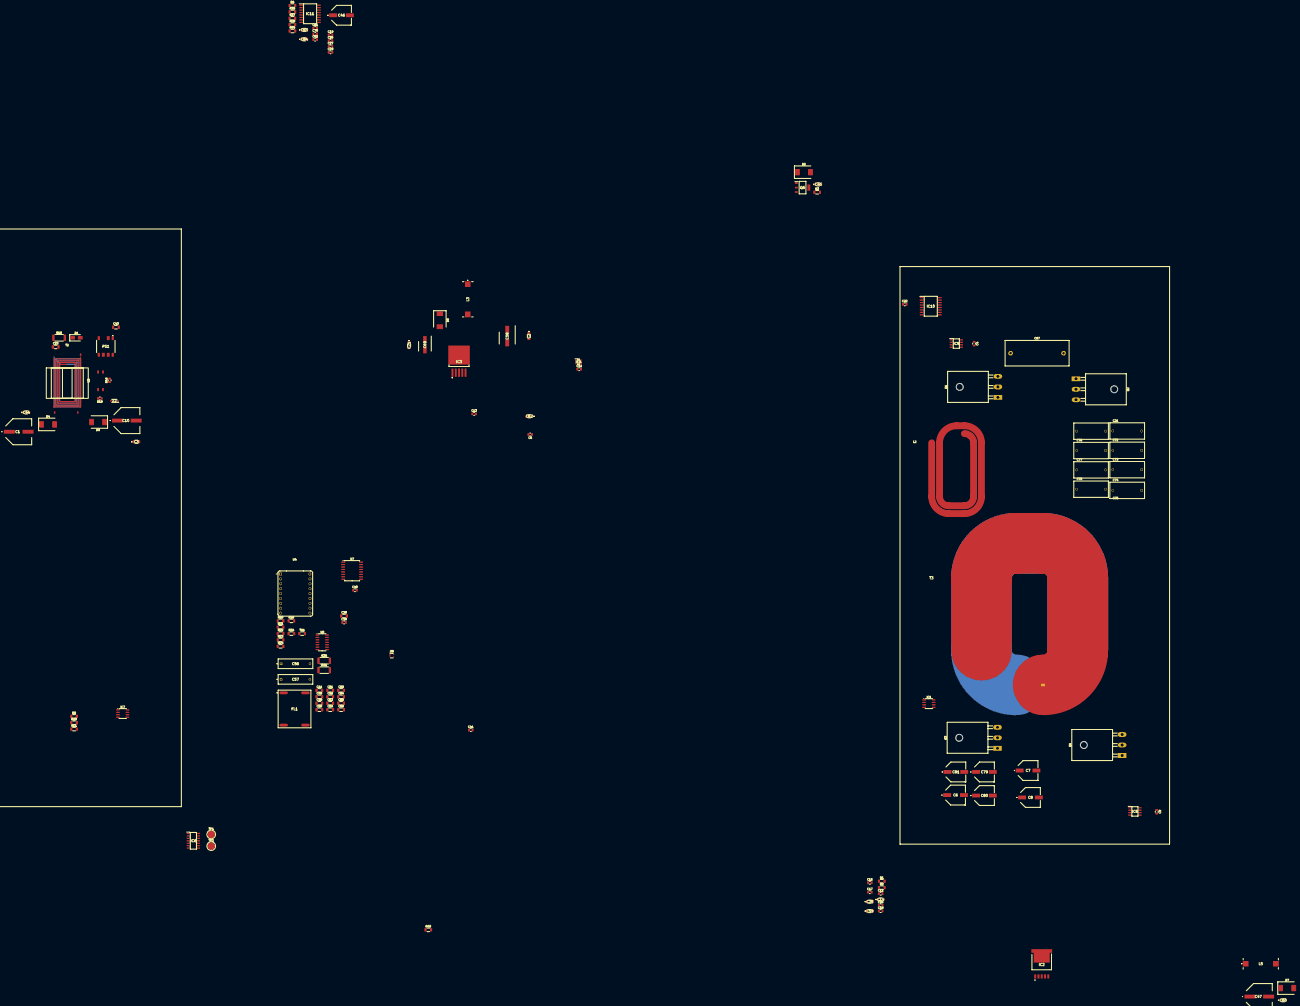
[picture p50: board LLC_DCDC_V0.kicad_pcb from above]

Board: 4 copper layers, 132 parts (0 on the bottom side), 70 nets, no tracks yet.

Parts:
C1, C10, C47: EEV-FK1V471Q; EEEFK0J332AQ
C2, C3, C14, C25, C44, C45, C59, C60, C62, C71, C83, C84: GRM31CR71E106KA12K; GRM31x
C4, C5, C9, C12, C13, C15, C16, C17, C18, C19, C20, C22, C39, C40, C41, C42, C61, C70, C82: SH21B104K101CT; C_0805_2012Metric
C6, C7, C8, C46, C79, C80, C81: B40910A8127M000
C11, C48, C49, C50, C51, C52, C53, C54, C55, C64, C65, C66: 885342208008; C_1206_3216Metric
C21, C72, C73, C74, C75, C76, C77, C78: B32672L8153J; CAPRR1500W80L1800T850H1450
C23: 10nF 630V; C_1206_3216Metric
C27, C29: 1n; C_0805_2012Metric
C38: 100nF; C_1206_3216Metric
C43: 10u 50v 1206; C_1206_3216Metric
C56, C57: R46KI310050M1K
C58: 875115350002; CAPAE830X770N
C67: 4uF 600VDC Film; C_Rect_L33.0mm_W13.0mm_P27.50mm_MKS4
C69: A768EB107M1ELAS036; CAPAE660X600N
D1: US1J; D_SMA
D2, D3, D4, D5, D7: MBRS340; D_SMC
FL1: PA2756NLT
IC1, IC7: NCP43080DDR2G; SOIC-8_3.9x4.9mm_P1.27mm
IC2: LM2575HVS-12_NOPB; LM2575HVS12NOPB
IC3: LM2575-3.3WU-TR; MIC29302WU
IC4: LT6654BIS6-2.048#TRMPBF; SOT95P280X100-6N
IC6: SN74HC74DRG4; SOIC127P600X175-14N
IC8: TMCS1107A1UQDRQ1; SOIC127P600X175-8N
IC9: ACS70331EOLCTR-005U3; SOIC127P600X175-8N
IC10: ISO7741BDWR; SOIC127P1030X265-16N
IC11: SI82390BD-IS; SOIC127P1030X265-16N
L2: ELP 43/10/28 & I 43/10/28; ELP_43_10_28
L3, L5: PM5022-331M-RC; PM5022331MRC
PS1: TNY280GN-TL; TNY280GNTL
Q1, Q2: IPW60R037CM8XKSA1; TO-247-3_Horizontal_TabDown
Q3, Q4: FDH055N15A; TO-247-3_Horizontal_TabDown
Q6: BCP5616H6327XTSA1; SOT230P700X180-4N
R1, R2, R9, R10, R11, R34, R36, R37, R38, R44: R; R_1206_3216Metric
R3: 330; R_1206_3216Metric
R4: 100K; R_1206_3216Metric
R18: 82K 2W; R_2512_6332Metric
R19: 1K 125mW; R_0805_2012Metric
R20, R21, R22, R23, R24: 100K 0.1% 520mW; R_1206_3216Metric
R25: 1K 0.1% 250mW; R_1206_3216Metric
R39, R41: 35203R9JT; R_2512_6332Metric
R40: 220 125mW; R_0805_2012Metric
R43: 10K; R_1206_3216Metric
T2: Transformer_1P_2S; Trans_planner_buck
T3: ELP/102/20/38 & I/102/38/20; ELP_102_20_38
TH1: Thermistor; R_1206_3216Metric
TP1, TP2: TestPoint; TestPoint_Pad_D4.0mm
U2: PC817A; PC817
U4: ESP32-S3-SuperMini; ESP32_S3_SuperMini
U7: AMC3330; SOIC-16W_7.5x10.3mm_P1.27mm
U8: TLV6001IDCKT; SOT-353_SC-70-5
U9: TLV9024QDRQ1; SOIC-14_3.9x8.7mm_P1.27mm
Z2: BZT52C11-7-F; SOD3716X145N

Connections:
+3.3V: C2.1, C4.1, C5.1, C9.1, C13.1, C14.1, C15.2, C20.1, C22.1, C39.1, C41.2, C58.1 (+), C61.1, IC3.4 (FB), IC4.4 (VIN), IC6.14 (VCC), IC8.8 (VS), IC9.8 (VCC), IC10.1 (VCC1), IC11.3 (VDDI_1), IC11.8 (VDDI_2), L3.2, R43.1, U7.12 (VDD), U8.5 (V+), U9.3 (V+)
+12drvPrim: C3.1, C10.1 (+), C45.1, C69.1 (+), C71.1, C82.1, C84.1, D2.1 (K), D3.1 (K), IC3.1 (VIN), IC11.11 (VDDB), R19.1, Z2.1 (K)
+12drvPrimH: C1.1 (+), C44.1, C70.1, C83.1, D4.1 (K), IC11.16 (VDDA)
+12drvSec: C12.1, C18.1, C25.1, C47.1 (+), C59.1, C60.1, IC1.1 (VCC), IC2.4 (FEEDBACK), IC7.1 (VCC), L5.2
CompOut: IC6.1 (~1CLR), R43.2, U9.1, U9.2, U9.13, U9.14
CurrInMes1: IC9.7 (VIOUT), U4.10 (GPIO10), U9.9 (+)
CurrOutMes1: IC8.7 (VOUT), U4.9 (GPIO9), U9.11 (+)
D_S_1: IC1.6 (CS), Q3.2 (D), T3.3 (SA)
D_S_2: IC7.6 (CS), Q4.2 (D), T3.5 (SD)
EN1: IC6.5 (1Q), IC11.5 (EN), R4.1, U4.5 (GPIO5)
GND2: C6.2 (-), C7.2 (-), C8.2 (-), C12.2, C17.1, C18.2, C19.1, C25.2, C46.2 (-), C47.2 (-), C59.2, C60.2, C79.1 (+), C80.1 (+), C81.1 (+), D7.2 (A), IC1.4 (LLD), IC1.7 (GND), IC2.3 (GROUND), IC2.5 (~ON/OFF), IC2.6 (GND_1), IC2.7 (GND_2), IC7.4 (LLD), IC7.7 (GND), Q3.3 (S), Q4.3 (S), R1.1, R2.1, R9.2, R10.2, U7.2 (DCDC_HGND), U7.7 (INN), U7.8 (HGND)
GND_IN: C48.1, C51.2, C64.1, C66.2, R39.2, R41.1
G_P_1: C70.2, C83.2, IC11.14 (GNDA), Q1.1 (G), R36.1, R38.1
G_P_2: Q2.1 (G), R37.1, R44.1
G_S_1: Q3.1 (G), R2.2
G_S_2: Q4.1 (G), R1.2, R11.1
HVN1: C2.2, C3.2, C5.2, C9.2, C10.2 (-), C13.2, C14.2, C15.1, C16.2, C20.2, C21.2, C22.2, C27.1, C38.1, C39.2, C41.1, C42.2, C43.2, C45.2, C50.1, C57.2, C58.2 (-), C61.2, C62.2, C67.2, C69.2 (-), C71.2, C72.2, C73.2, C74.2, C75.2, C76.2, C77.2, C78.2, C82.2, C84.2, D5.2 (A), FL1.4 (N2-), IC3.3 (GND), IC3.5 (~ON/OFF), IC3.6 (TAB), IC4.1 (GND_1), IC4.2 (GND_2), IC6.2 (1D), IC6.3 (1CLK), IC6.7 (GND), IC6.10 (2~PRE), IC6.11 (2CLK), IC6.12 (2D), IC6.13 (2~CLR), IC8.5 (GND), IC10.8 (GND1_2), IC11.4 (GNDI), IC11.9 (GNDB), PS1.5 (S_1), PS1.6 (S_2), PS1.7 (S_3), PS1.8 (S_4), Q2.3 (S), Q6.2 (C_1), Q6.4 (C_2), R4.2, R25.2, R40.2, R44.2, T2.6 (SD), TH1.2, TP2.1, U2.3, U7.9 (GND), U7.15 (DCDC_GND), U8.2 (V-), U9.12 (V-)
HVN_IN: C54.1, C56.2, FL1.3 (N2+)
HVP1: C23.1, C67.1, IC9.3 (IP-_1), IC9.4 (IP-_2), Q1.2 (D), R18.1, R20.1, T2.1 (AA), TP1.1
HVP2: C57.1, FL1.2 (N1-), IC9.1 (IP+_1), IC9.2 (IP+_2)
HVP_IN: C11.2, C53.2, C56.1, FL1.1 (N1+)
unnamed: C11.1, C64.2
unnamed: C48.2, C49.1
unnamed: C50.2, C51.1
unnamed: C52.1, R41.2
unnamed: C52.2, C53.1
unnamed: C54.2, C55.1
unnamed: C55.2, R39.1
unnamed: C65.2, C66.1
unnamed: D1.2 (A), PS1.4 (D), T2.2 (AB)
unnamed: C23.2, D1.1 (K), R18.2
unnamed: D2.2 (A), Q6.3 (E)
unnamed: D3.2 (A), T2.5 (SC)
unnamed: D4.2 (A), T2.3 (SA)
unnamed: D5.1 (K), IC3.2 (OUT), L3.1
unnamed: D7.1 (K), IC2.2 (OUTPUT), L5.1
unnamed: IC7.8 (DRV), R11.2
unnamed: IC7.2 (MIN_TOFF), R9.1
unnamed: IC7.3 (MIN_TON), R10.1
unnamed: C4.2, IC9.5 (GND)
unnamed: C40.2, IC10.9 (GND2_1)
unnamed: C40.1, IC10.16 (VCC2)
unnamed: IC11.15 (VOA), R36.2
unnamed: IC11.10 (VOB), R37.2
unnamed: C43.1, PS1.2 (BP/M)
unnamed: PS1.1 (EN/UV), U2.4
unnamed: Q6.1 (B), R3.1
unnamed: R20.2, R21.1
unnamed: R21.2, R22.1
unnamed: R22.2, R23.1
unnamed: R23.2, R24.1
unnamed: R40.1, U2.2
unnamed: L2.1, T3.1 (AA)
unnamed: C21.1, C72.1, C73.1, C74.1, C75.1, C76.1, C77.1, C78.1, T3.2 (AB)
unnamed: C16.1, U7.13 (LDO_OUT), U7.16 (DCDC_IN)
unnamed: C19.2, U7.1 (DCDC_OUT), U7.3 (HLDO_IN)
unnamed: C17.2, U7.5 (HLDO_OUT)
unnamed: C27.2, U8.1 (+)
unnamed: C29.1, U8.3 (-)
unnamed: R19.2, U2.1, Z2.2 (A)
OUT1: C6.1 (+), C7.1 (+), C8.1 (+), C46.1 (+), C79.2 (-), C80.2 (-), C81.2 (-), IC2.1 (VIN), IC8.1 (IN+_1), IC8.2 (IN+_2), T3.4 (SC)
OUT2: IC8.3 (IN-_1), IC8.4 (IN-_2)
RDY1: IC11.7 (RDY), U4.6 (GPIO6)
ResMuc: IC6.4 (1~PRE), U4.2 (GPIO2)
S_P_1: C1.2 (-), C44.2, L2.2, Q1.3 (S), Q2.2 (D), R38.2, T2.4 (SB)
ThermMes1: R34.2, TH1.1, U4.3 (GPIO3)
VinMes1: R24.2, R25.1, U4.13 (GPIO13), U9.5 (+)
VoutMeasDiag: U4.11 (GPIO11), U7.14 (DIAG)
VoutMes1: C29.2, U4.12 (GPIO12), U8.4, U9.7 (+)
Vref33: C42.1, C62.1, IC4.6 (VOUT), R34.1, U4.7 (GPIO7)

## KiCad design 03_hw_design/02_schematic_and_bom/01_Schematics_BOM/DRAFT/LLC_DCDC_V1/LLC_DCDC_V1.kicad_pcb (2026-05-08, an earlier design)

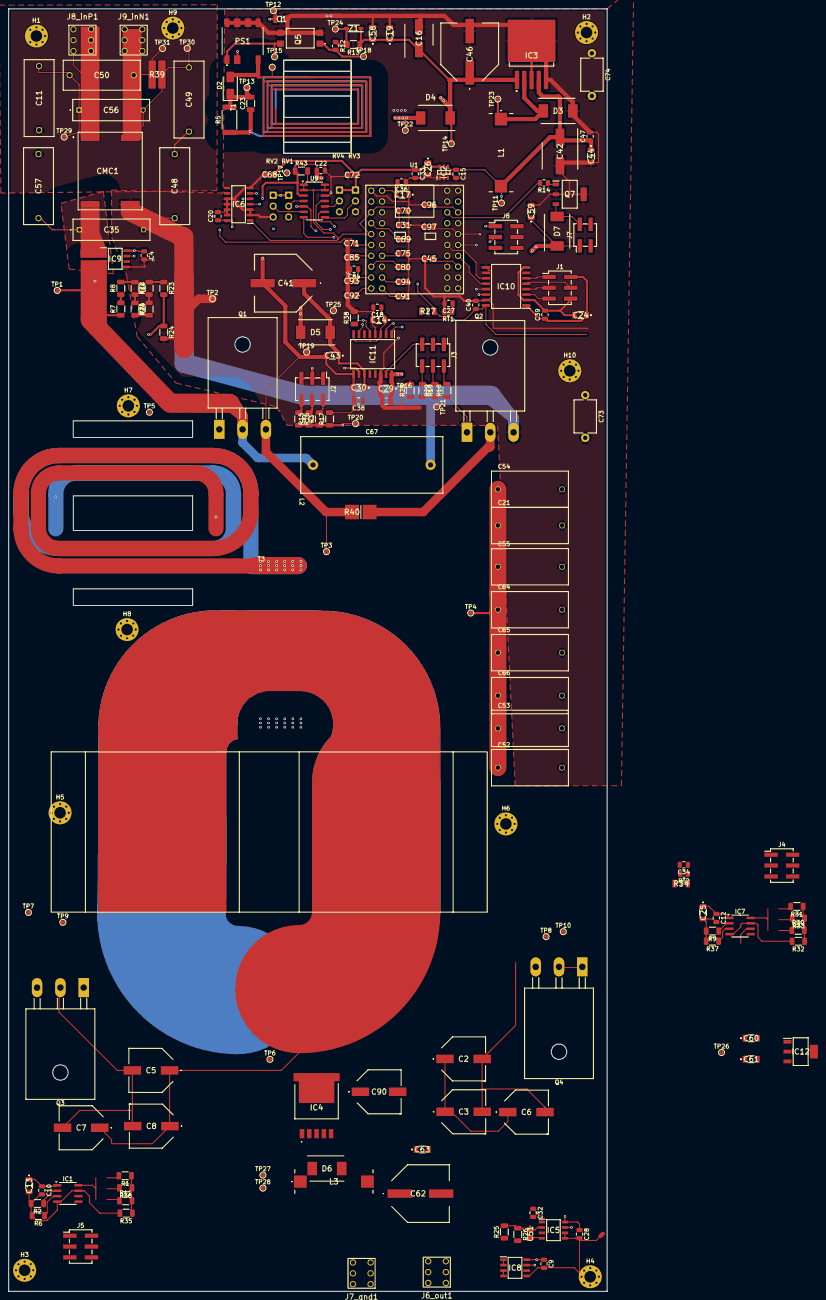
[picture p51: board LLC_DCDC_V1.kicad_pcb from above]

Board: 4 copper layers, 140.0 x 300.0 mm, 217 parts (0 on the bottom side), 93 nets.

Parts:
C1: CL31A106KBHNNNE; CAPC3216X180N
C2, C3, C5, C6, C7, C8, C90: B40910A8127M000
C4, C9, C10, C12, C15, C18, C20, C22, C27, C28, C32, C33, C34, C36, C37, C38, C39, C40, C47, C84: SH21B104K101CT; C_0805_2012Metric
C11, C48, C49, C50, C57: B81123C1222M
C13, C14, C17, C19, C24, C25, C26, C29, C30, C43, C44, C58, C59, C60, C61, C63: GRM31CR71E106KA12K; GRM31x
C16: A768EB107M1ELAS036; CAPAE660X600N
C21, C52, C53, C54, C55, C64, C65, C66: B32672L8153J; CAPRR1500W80L1800T850H1450
C23: AC1206JKNPOZBN103; C_1206_3216Metric
C31, C45, C51, C68, C69, C70, C71, C72, C75, C80, C85, C91, C92, C93, C94, C96, C97: C0805C102J5GACTU; C0805
C35, C56: R46KI310050M1K
C41, C46, C62: EEV-FK1V471Q; EEEFK0J332AQ
C42: 875115350002; CAPAE830X770N
C67: EFDKS60K405D032LH; C_Rect_L33.0mm_W13.0mm_P27.50mm_MKS4
C73, C74: VY1221K31Y5SQ6TV0; C_Disc_D7.5mm_W5.0mm_P10.00mm
CMC1: PA2750NL
D2: US1J; D_SMA
D3, D4, D5, D6, D7: MBRS340T3G; DIOM8059X261N
H1, H2, H3, H4, H5, H6, H7, H8, H9, H10: MountingHole_2.7mm_M2.5_Pad_Via
IC1, IC7: NCP43080DDR2G; SOIC-8_3.9x4.9mm_P1.27mm
IC2: LT6654BIS6-2.048#TRMPBF; SOT95P280X100-6N
IC3: LM2575-3.3WU-TR; MIC29302WU
IC4: LM2575HVS-12_NOPB; LM2575HVS12NOPB
IC5: SI8932B-IS; SOIC127P600X175-8N
IC6: SN74HC74DRG4; SOIC127P600X175-14N
IC8: TMCS1107A1UQDRQ1; SOIC127P600X175-8N
IC9: ACS70331EOLCTR-005U3; SOIC127P600X175-8N
IC10: ISO7741BDWR; SOIC127P1030X265-16N
IC11: SI82390BD-IS; SOIC127P1030X265-16N
IC12: AZ1117CH2-3.3TRG1; SOT230P700X180-4N
J1: Conn_02x03; PinHeader_2x03_P2.54mm_Vertical_SMD
J2, J3, J4, J5, J8: jumper_02x03; PinHeader_2x03_P2.54mm_Vertical_SMD
J6_out1, J7_gnd1, J8_inP1, J9_inN1: Screw_Terminal_01x01; tab_conn
J7: Conn_02x02_Odd_Even; PinHeader_2x02_P2.54mm_Vertical_SMD
L1, L3: PM5022-331M-RC; PM5022331MRC
L2: B66461G0000X187; ELP_43_10_28_v2
PS1: TNY280GN-TL; TNY280GNTL
Q1, Q2: IPW60R037CM8XKSA1; TO-247-3_Horizontal_TabDown
Q3, Q4: FDH055N15A; TO-247-3_Horizontal_TabDown
Q5: DPC817S-B-TR; DPC817SBTR
Q7: BCP5616H6327XTSA1; SOT230P700X180-4N
R1, R16, R19, R31: KTR18EZPJ3R0; R_1206_3216Metric
R2, R6, R9, R17, R28, R32, R35, R37, R38, R43: RC1206FR-0711K5L; R_1206_3216Metric
R3, R18: RNCE1206BTE10R0; R_1206_3216Metric
R5: 9-2176070-5; R_2512_6332Metric
R7, R8, R10, R20, R21, R22, R23, R25: RT1206BRD0756KL; R_1206_3216Metric
R11, R30: CRCW12060000Z0EAC; R_1206_3216Metric
R12, R14: SFR10EZPF2200; R_0805_2012Metric
R13: CR1206-FX-1071ELF; R_1206_3216Metric
R15, R29: M251206BB5108JP500; R_1206_3216Metric
R24: RNCE1206BTE1K00; R_1206_3216Metric
R26: ERA-8AEB152V; R_1206_3216Metric
R27, R34: RN73R2BTTD4991B25; RESC3216X70N
R33, R36: RC1206JR-071R1L; R_1206_3216Metric
R39: LTR100JZPJ270; RESC3264X70N
R40: LRMAP2512-R007FT4; RESC6432X90N
RT1, RT2: TX08F103F3435ER; R_0805_2012Metric
RV1, RV2, RV3, RV4: RV_precision
T1: B66285G0000X187,B66285K0000X187; Trans_planner_buck
T3: B66297K0000X197,B66297G0000X197; ELP_102_20_38_V6
TP1, TP2, TP3, TP4, TP5, TP6, TP7, TP8, TP9, TP10, TP11, TP12, TP13, TP14, TP15, TP16, TP17, TP18, TP19, TP20, TP21, TP22, TP23, TP24, TP25, TP26, TP27, TP28, TP29, TP30, TP31: TestPoint; TestPoint_Pad_D1.0mm
U1: stm32F103C8T6-CH340; SMT32F1-MINI
U9: TLV9024QDRQ1; SOIC-14_3.9x8.7mm_P1.27mm
Z1: BZT52C11-7-F; SOD3716X145N

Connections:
3.3v_or_5v_extern: C24.1, C39.1, IC10.1 (VCC1), J1.2
+3.3V: C4.1, C9.1, C14.1, C15.1, C17.2, C18.1, C20.1, C22.1, C28.1, C36.2, C40.1, C42.1 (+), C44.1, C47.1, IC2.4 (VIN), IC3.4 (FB), IC5.8 (VDDB), IC6.14 (VCC), IC8.8 (VS), IC9.8 (VCC), IC10.16 (VCC2), IC11.3 (VDDI_1), IC11.8 (VDDI_2), J8.1, L1.2, R43.1, TP11.1, U1.11 (3v3), U9.3 (V+)
+3.3V_second: C32.1, C61.1, IC5.1 (VDDA), IC12.3 (OUTPUT), TP26.1
+12drvPrim: C16.1 (+), C19.1, C29.1, C37.1, C46.1 (+), C58.1, C59.1, D4.1 (K), D7.1 (K), IC3.1 (VIN), IC11.16 (VDDA), J7.1, J7.3, R13.1, TP14.1, Z1.1 (K)
+12drvPrimH: C30.1, C38.1, C41.1 (+), C43.1, D5.1 (K), IC11.11 (VDDB), TP25.1
+12drvSec: C10.1, C12.1, C13.1, C25.1, C60.1, C62.1 (+), C63.1, IC1.1 (VCC), IC4.4 (FEEDBACK), IC7.1 (VCC), IC12.1 (INPUT), L3.2, TP28.1
CompOut: C31.2, C70.2, IC6.1 (~1CLR), R43.2, U1.3 (b12), U1.5 (b1), U9.1, U9.2, U9.13, U9.14
CurrInMes1: C80.1, IC9.7 (VIOUT), U1.8 (A5), U9.9 (+)
CurrOutMes1: C91.1, IC8.7 (VOUT), U1.20 (A0), U9.11 (+)
D_S_H: IC1.6 (CS), Q3.2 (D), TP7.1
D_S_L: IC7.6 (CS), Q4.2 (D), TP8.1
EN1: IC6.5 (1Q), IC11.5 (EN), R38.1, U1.24 (A12)
FeedbacktoMCU: C71.2, IC6.6 (1~Q), U1.6 (b0)
GND2: C2.2 (-), C3.2 (-), C5.2 (-), C6.2 (-), C7.2 (-), C8.2 (-), C10.2, C12.2, C13.2, C25.2, C32.2, C34.2, C51.2, C60.2, C61.2, C62.2 (-), C63.2, C73.1, C74.1, C90.2 (-), D6.2 (A), H1.1, H2.1, H3.1, H4.1, H5.1, H6.1, H7.1, H8.1, H9.1, H10.1, IC1.4 (LLD), IC1.7 (GND), IC4.3 (GROUND), IC4.5 (~ON/OFF), IC4.6 (GND_1), IC4.7 (GND_2), IC5.4 (GNDA), IC7.4 (LLD), IC7.7 (GND), IC12.2 (ADJ/GND_1), IC12.4 (ADJ/GND_2), J7_gnd1.1, Q3.3 (S), Q4.3 (S), R2.2, R6.2, R9.2, R26.2, R32.2, R35.2, R37.2, RT2.2
GND_IN: C11.1, C48.2, C49.2, C57.1
GND_ISO: C1.2, C4.2, C9.2, C14.2, C15.2, C16.2 (-), C17.1, C18.2, C19.2, C20.2, C21.2, C22.2, C26.2, C27.2, C28.2, C29.2, C31.1, C33.2, C35.2, C36.1, C37.2, C40.2, C42.2 (-), C44.2, C45.2, C46.2 (-), C47.2, C48.1, C52.2, C53.2, C54.2, C55.2, C58.2, C59.2, C64.2, C65.2, C66.2, C67.2, C68.2, C69.1, C70.1, C71.1, C72.2, C73.2, C74.2, C75.2, C80.2, C84.2, C85.2, C91.2, C92.2, C93.2, C94.2, C96.1, C97.1, CMC1.4 (SEC_2), D3.2 (A), IC2.1 (GND_1), IC2.2 (GND_2), IC3.3 (GND), IC3.5 (~ON/OFF), IC3.6 (TAB), IC5.5 (GNDB_1), IC5.6 (GNDB_2), IC6.2 (1D), IC6.3 (1CLK), IC6.7 (GND), IC6.10 (2~PRE), IC6.11 (2CLK), IC6.12 (2D), IC6.13 (2~CLR), IC8.5 (GND), IC9.5 (GND), IC10.9 (GND2_1), IC10.15 (GND2_2), IC11.4 (GNDI), IC11.14 (GNDA), J8.5, PS1.5 (S_1), PS1.6 (S_2), PS1.7 (S_3), PS1.8 (S_4), Q2.3 (S), Q5.2 (K), Q5.3 (E), Q7.2 (C_1), Q7.4 (C_2), R24.2, R28.2, R38.2, RT1.2, RV1.3, RV2.3, RV3.3, RV4.3, TP2.1, U1.1 (gnd), U9.12 (V-)
GND_extern: C24.2, C39.2, IC10.2 (GND1_1), IC10.8 (GND1_2), J1.6
G_P_H: Q1.1 (G), R3.1, R15.1, R16.2, R17.1, TP20.1
G_P_L: Q2.1 (G), R18.1, R19.2, R28.1, R29.1, TP21.1
G_S_H: Q3.1 (G), R1.1, R11.2, R35.1, R36.1, TP9.1
G_S_L: Q4.1 (G), R30.2, R31.1, R32.1, R33.1, TP10.1
HVN_IN: C49.1, C56.2, CMC1.3 (SEC_1), J9_inN1.1, R39.2, TP30.1
HVP1: C23.1, C67.1, IC9.3 (IP-_1), IC9.4 (IP-_2), Q1.2 (D), R5.1, R7.1, TP1.1
HVP2: C35.1, C57.2, CMC1.2 (PRI_2), IC9.1 (IP+_1), IC9.2 (IP+_2)
HVP_IN: C11.2, C50.1, C56.1, CMC1.1 (PRI_1), J8_inP1.1, TP29.1
MISO: IC10.11 (IND), U1.26 (B4)
MISO_extern: IC10.6 (OUT_D), J1.1
MOSI: IC10.12 (OUT_C), U1.37 (B5)
MOSI_extern: IC10.5 (INC), J1.4
MUC_FAN_CTR: R14.2, U1.23 (A10)
NSS: C97.2, IC10.14 (OUT_A), U1.35 (A15)
NSS_extern: IC10.3 (INA), J1.5
unnamed: C50.2, R39.1, TP31.1
unnamed: D2.2 (A), PS1.4 (D), TP16.1
unnamed: C23.2, D2.1 (K), R5.2, TP13.1
unnamed: D3.1 (K), IC3.2 (OUT), L1.1, TP23.1
unnamed: D4.2 (A), TP22.1
unnamed: D5.2 (A), TP19.1
unnamed: D6.1 (K), IC4.2 (OUTPUT), L3.1, TP27.1
unnamed: D7.2 (A), J7.2, J7.4, Q7.3 (E)
unnamed: IC1.2 (MIN_TOFF), R2.1
unnamed: IC1.3 (MIN_TON), R6.1
unnamed: C51.1, IC5.2 (VIN), R25.2, R26.1
unnamed: IC7.2 (MIN_TOFF), R9.1
unnamed: IC7.3 (MIN_TON), R37.1
unnamed: J2.2, R3.2
unnamed: J2.4, R15.2
unnamed: J2.6, R16.1
unnamed: J3.2, R18.2
unnamed: J3.4, R29.2
unnamed: J3.6, R19.1
unnamed: J4.2, R31.2
unnamed: J4.4, R33.2
unnamed: J4.6, R30.1
unnamed: J5.2, R1.2
unnamed: J5.4, R36.2
unnamed: J5.6, R11.1
unnamed: C45.1, J8.3, U1.38 (B7)
unnamed: C1.1, PS1.2 (BP/M), TP12.1
unnamed: PS1.1 (EN/UV), Q5.4 (C), TP15.1
unnamed: Q2.2 (D), R40.2
unnamed: Q5.1 (A), R12.2, TP18.1
unnamed: Q7.1 (B), R14.1
unnamed: R7.2, R8.1
unnamed: R8.2, R10.1
unnamed: R10.2, R20.1
unnamed: R20.2, R21.1
unnamed: R21.2, R22.1
unnamed: R22.2, R23.1
unnamed: C21.1, C52.1, C53.1, C54.1, C55.1, C64.1, C65.1, C66.1, TP4.1
unnamed: RV2.2, U9.6 (-)
unnamed: RV1.2, U9.4 (-)
unnamed: RV3.2, U9.8 (-)
unnamed: RV4.2, U9.10 (-)
unnamed: R12.1, R13.2, TP24.1, Z1.2 (A)
OUT1: C2.1 (+), C3.1 (+), C5.1 (+), C6.1 (+), C7.1 (+), C8.1 (+), C90.1 (+), IC4.1 (VIN), IC8.1 (IN+_1), IC8.2 (IN+_2), R25.1, TP6.1
OUT2: IC8.3 (IN-_1), IC8.4 (IN-_2), J6_out1.1
RDY1: C96.2, IC11.7 (RDY), U1.33 (A11)
ResMuc: C69.2, IC6.4 (1~PRE), U1.4 (b10)
SCK: IC10.13 (OUT_B), U1.36 (B3)
SCK_extern: IC10.4 (INB), J1.3
S_P_H: C30.2, C38.2, C41.2 (-), C43.2, IC11.9 (GNDB), Q1.3 (S), R17.2, R40.1, TP3.1
ThermMes_P: C27.1, C94.1, R27.2, RT1.1, U1.19 (A2)
ThermMes_S: C34.1, C75.1, R34.2, RT2.1, U1.17 (A6)
To_Jum_H: IC11.10 (VOB), J2.1, J2.3, J2.5
To_Jum_L: IC11.15 (VOA), J3.1, J3.3, J3.5
To_Jum_SH: IC1.8 (DRV), J5.1, J5.3, J5.5
To_Jum_SL: IC7.8 (DRV), J4.1, J4.3, J4.5
VIA: IC11.1 (VIA), U1.32 (A9)
VIB: IC11.2 (VIB), U1.2 (b14)
VinMes1: C85.1, R23.2, R24.1, U1.7 (A7), U9.5 (+)
VoutMes1: C92.1, IC5.7 (AO), U1.10 (A1), U9.7 (+)
Vref2048: C26.1, C33.1, C68.1, C72.1, C84.1, C93.1, IC2.6 (VOUT), R27.1, R34.1, RV1.1, RV2.1, RV3.1, RV4.1, TP17.1, U1.9 (A3)

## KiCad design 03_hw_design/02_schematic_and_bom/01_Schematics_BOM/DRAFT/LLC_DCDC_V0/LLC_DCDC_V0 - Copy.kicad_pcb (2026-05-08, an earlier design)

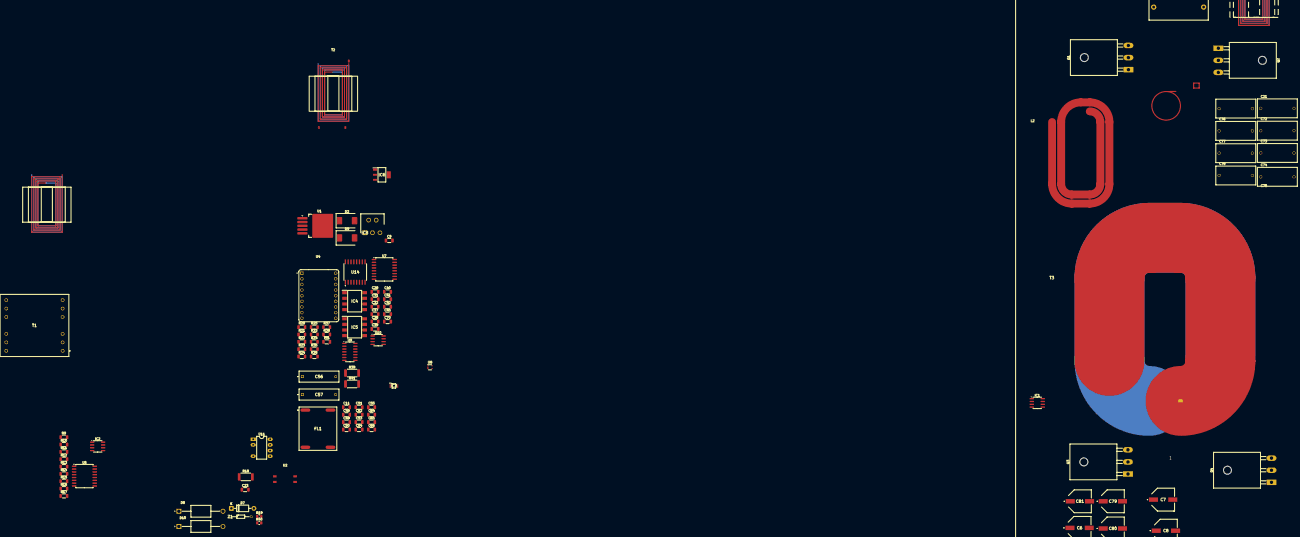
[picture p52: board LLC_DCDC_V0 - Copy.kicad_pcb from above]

Board: 4 copper layers, 101 parts (0 on the bottom side), 72 nets, no tracks yet.

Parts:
C6, C7, C8, C79, C80, C81: B40910A8127M000
C9, C28, C31, C32, C37, C38, C42, C45, C70: 100nF; C_1206_3216Metric
C11, C48, C49, C50, C51, C52, C53, C54, C55, C64, C65, C66: 885342208008; C_1206_3216Metric
C21, C72, C73, C74, C75, C76, C77, C78: B32672L8153J; CAPRR1500W80L1800T850H1450
C23: 10nF 630V; C_1206_3216Metric
C39: 1nF; C_1206_3216Metric
C40: 1uF; C_1206_3216Metric
C41: 10nF; C_1206_3216Metric
C56, C57: R46KI310050M1K
Cdc1: 4uF +/-5% 700V; C_Rect_L26.5mm_W11.5mm_P22.50mm_MKS4
D2, D9: MBRS340; D_SMC
D7: 1N4937; D_DO-41_SOD81_P10.16mm_Horizontal
D8, D10: UG4D; DIOAD1990W125L900D530
FL1: PA2756NLT
IC1, IC2: NCP43080ADR2G; SOIC-8_3.9x4.9mm_P1.27mm
IC3: 74LVC1G74DC,125; SOP50P310X100-8N
IC4, IC5: 6N137S-TA1; SOP254P1016X460-8N
IC6: AZ1117CH2-3.3TRG1; SOT230P700X180-4N
IC8: LM2575HVT-12_LF03; TO170P470X1028X2142-5P
L2: ELP 43/10/28 & I 43/10/28; ELP_43_10_28
Q1, Q2: IPW60R037CM8XKSA1; TO-247-3_Horizontal_TabDown
Q3, Q4: FDH055N15A; TO-247-3_Horizontal_TabDown
R9, R10, R11, R12, R13, R14, R15, R16, R17, R34, R35, R36, R37, R38: R; R_1206_3216Metric
R18: 82K 2W; R_2512_6332Metric
R19: 1K 125mW; R_0805_2012Metric
R20, R21, R22, R23, R24: 100K 0.1% 520mW; R_1206_3216Metric
R25: 1K 0.1% 250mW; R_1206_3216Metric
R33: 100k; R_1206_3216Metric
R39, R41: 35203R9JT; R_2512_6332Metric
R40: 220 125mW; R_0805_2012Metric
T1: 11328-T074; 11328T074
T2: Transformer_1P_2S; Trans_planner_buck
T3: ELP/102/20/38 & I/102/38/20; ELP_102_20_38
TH1: Thermistor; R_1206_3216Metric
U1: LM2575-5.0BU; TO-263-5_TabPin3
U2: PC817A; PC817
U4: ESP32-S3-SuperMini; ESP32_S3_SuperMini
U5: SI82394AD-IS; SOIC-16W_7.5x10.3mm_P1.27mm
U7: AMC3330; SOIC-16W_7.5x10.3mm_P1.27mm
U8: TLV6001IDCKT; SOT-353_SC-70-5
U9: TLV9024QDRQ1; SOIC-14_3.9x8.7mm_P1.27mm
U10: ACHS-7121-000E; SOIC-8_3.9x4.9mm_P1.27mm
U11: TNY279P; PowerIntegrations_PDIP-8C
U14: MCR1101-50-5; MCR1101505
Z1: BZX55C11-TR; DIOAD950W60L350D150

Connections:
+3.3V: C70.2, IC3.8 (VCC), IC5.7 (VE), IC5.8 (VCC), IC6.3 (OUTPUT), R37.2, U7.12 (VDD)
+5V: C37.2, C38.2, C40.1, C42.2, C45.1, IC6.1 (INPUT), U1.4 (FB), U5.3 (VDDI), U5.8 (VDDI), U8.5 (V+), U9.3 (V+), U10.8 (VDD), U14.10 (VCC)
+12drvPrim: U1.1 (VIN), U5.11 (VDDB)
+12drvSec: C9.1, IC1.1 (VCC), IC2.1 (VCC), IC8.4 (FEEDBACK)
CompOut: IC3.7 (~SD), R33.2, U9.1, U9.2, U9.13, U9.14
CurrInMes1: U4.10 (GPIO10), U9.9 (+), U10.7 (VOUT)
CurrOutFault: U4.8 (GPIO8), U14.9 (~FAULTB)
CurrOutMes1: U4.9 (GPIO9), U14.12 (VOUT)
D_S_1: IC1.6 (CS), Q3.2 (D), T3.3 (SA)
D_S_2: IC2.6 (CS), Q4.2 (D), T3.5 (SD)
EN1: IC3.3 (~Q), R17.1, U4.5 (GPIO5), U5.5 (EN)
GND_IN: C48.1, C51.2, C64.1, C66.2, R39.2, R41.1
G_P_1: Q1.1 (G), R12.1, R13.1, U5.14 (GNDA)
G_P_2: Q2.1 (G), R14.1, R15.1
G_S_2: Q4.1 (G), R11.1
HVN1: C21.2, C28.2, C37.1, C38.1, C42.1, C45.2, C50.1, C57.2, C70.1, C72.2, C73.2, C74.2, C75.2, C76.2, C77.2, C78.2, Cdc1.2, D2.2 (A), FL1.4 (N2-), IC3.1 (CP), IC3.2 (D), IC3.4 (GND), IC4.3 (CATHODE), IC5.5 (GND), IC6.2 (ADJ/GND_1), IC6.4 (ADJ/GND_2), Q2.3 (S), R15.2, R16.2, R17.2, R25.2, R40.2, TH1.2, U1.3 (GND), U1.5 (~ON/OFF), U2.3, U5.4 (GNDI), U5.9 (GNDB), U7.9 (GND), U7.15 (DCDC_GND), U8.2 (V-), U9.12 (V-), U11.5 (S), U11.6 (S), U11.7 (S), U11.8 (S), U14.11 (GND_1), U14.14 (GND_2), U14.15 (GND_3)
HVN_IN: C54.1, C56.2, FL1.3 (N2+)
HVP1: C23.1, Cdc1.1, Q1.2 (D), R18.1, R20.1, T1.3 (PRI_NP_2), U10.3 (IpN), U10.4 (IpN)
HVP2: C57.1, FL1.2 (N1-), U10.1 (IpP), U10.2 (IpN)
HVP_IN: C11.2, C53.2, C56.1, FL1.1 (N1+)
unnamed: C11.1, C64.2
unnamed: C48.2, C49.1
unnamed: C50.2, C51.1
unnamed: C52.1, R41.2
unnamed: C52.2, C53.1
unnamed: C54.2, C55.1
unnamed: C55.2, R39.1
unnamed: C65.2, C66.1
unnamed: D2.1 (K), U1.2 (OUT)
unnamed: D7.2 (A), T1.1 (PRI_NP_1), U11.4 (D)
unnamed: C23.2, D7.1 (K), R18.2
unnamed: D9.1 (K), IC8.2 (OUTPUT)
unnamed: IC2.8 (DRV), R11.2
unnamed: IC2.2 (MIN_TOFF), R9.1
unnamed: IC2.3 (MIN_TON), R10.1
unnamed: IC4.2 (ANODE), R35.1
unnamed: IC5.2 (ANODE), R36.2
unnamed: R20.2, R21.1
unnamed: R21.2, R22.1
unnamed: R22.2, R23.1
unnamed: R23.2, R24.1
unnamed: R40.1, U2.2
unnamed: D8.A, D10.A, T1.8 (SEC_NS_1), T1.9 (SEC_NS_2)
unnamed: T1.10 (SEC_NS_3), T1.11 (SEC_NS_4)
unnamed: L2.1, T3.1 (AA)
unnamed: C21.1, C72.1, C73.1, C74.1, C75.1, C76.1, C77.1, C78.1, T3.2 (AB)
unnamed: R16.1, U5.6 (DT)
unnamed: R12.2, U5.15 (VOA)
unnamed: R14.2, U5.10 (VOB)
unnamed: C28.1, U7.13 (LDO_OUT), U7.16 (DCDC_IN)
unnamed: C31.1, U7.1 (DCDC_OUT), U7.3 (HLDO_IN)
unnamed: C32.1, U7.5 (HLDO_OUT)
unnamed: C39.1, U10.6 (FILTER)
unnamed: C39.2, C40.2, U10.5 (GND)
unnamed: U2.4, U11.1 (EN/UV)
unnamed: C41.1, U14.13 (VCAP)
unnamed: R19.2, U2.1, Z1.2 (A)
unnamed: D8.C, D10.C, R19.1, Z1.1 (K)
OUT1: C6.1 (+), C7.1 (+), C8.1 (+), C79.2 (-), C80.2 (-), C81.2 (-), IC8.1 (VIN), T3.4 (SC), U14.1 (IP+_1), U14.2 (IP+_2), U14.3 (IP+_3), U14.4 (IP+_4)
OUT2: U14.5 (IP-_1), U14.6 (IP-_2), U14.7 (IP-_3), U14.8 (IP-_4)
RDY1: U4.6 (GPIO6), U5.7 (RDY)
RX: IC5.6 (VO), R37.1
ResMuc: IC3.6 (~RD), U4.2 (GPIO2)
S_P_1: L2.2, Q1.3 (S), Q2.2 (D), R13.2
ThermMes1: R34.2, TH1.1, U4.3 (GPIO3), U9.11 (+)
VinMes1: R24.2, R25.1, U4.13 (GPIO13), U9.5 (+)
VoutMeasDiag: U4.11 (GPIO11), U7.14 (DIAG)
VoutMes1: U4.12 (GPIO12), U8.4, U9.7 (+)
Vref33: R33.1, R34.1, U4.7 (GPIO7)
con_RX: IC4.6 (VO), R38.1
con_gnd: C6.2 (-), C7.2 (-), C8.2 (-), C9.2, C31.2, C32.2, C41.2, C79.1 (+), C80.1 (+), C81.1 (+), D9.2 (A), IC1.4 (LLD), IC1.7 (GND), IC2.4 (LLD), IC2.7 (GND), IC4.5 (GND), IC5.3 (CATHODE), IC8.3 (GROUND), IC8.5 (~ON/OFF), Q3.3 (S), Q4.3 (S), R9.2, R10.2, U7.2 (DCDC_HGND), U7.7 (INN), U7.8 (HGND)
con_vcc: IC4.7 (VE), IC4.8 (VCC), R38.2

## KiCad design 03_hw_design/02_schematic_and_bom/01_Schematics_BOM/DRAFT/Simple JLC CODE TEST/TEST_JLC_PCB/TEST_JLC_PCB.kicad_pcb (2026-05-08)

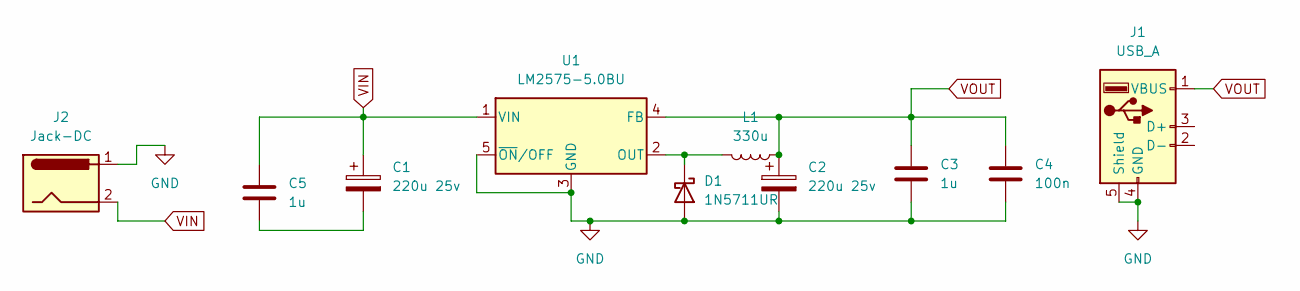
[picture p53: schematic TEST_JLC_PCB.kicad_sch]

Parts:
C1: 220u 25v; CP_Elec_6.3x7.7
C2: 220u 25v; CP_Elec_6.3x3
C3, C5: 1u; C_1206_3216Metric
C4: 100n; C_1206_3216Metric
D1: 1N5711UR; D_SMA
J1: USB_A; USB_A_Molex_67643_Horizontal
J2: Jack-DC; BarrelJack_CUI_PJ-063AH_Horizontal
L1: 330u; L_APV_APH1040
U1: LM2575-5.0BU; TO-263-5_TabPin3

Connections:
GND: C2.2, C3.2, C4.2, D1.2 (A), J1.4 (GND), J1.5 (Shield), J2.1, U1.3 (GND), U1.5 (~ON/OFF)
unnamed: C1.2, C5.2
unnamed: D1.1 (K), L1.2, U1.2 (OUT)
VIN: C1.1, C5.1, J2.2, U1.1 (VIN)
VOUT: C2.1, C3.1, C4.1, J1.1 (VBUS), L1.1, U1.4 (FB)

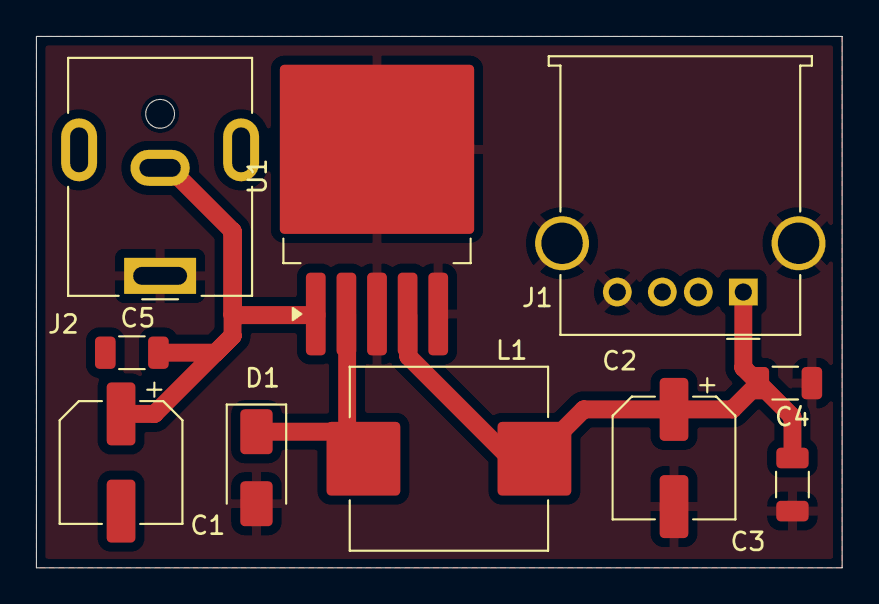
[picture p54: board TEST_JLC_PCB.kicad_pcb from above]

Board: 2 copper layers, 44.8 x 29.5 mm, 10 parts (0 on the bottom side), 5 nets.

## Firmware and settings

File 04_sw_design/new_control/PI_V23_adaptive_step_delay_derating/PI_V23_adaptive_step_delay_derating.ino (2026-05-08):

#include "stm32f1xx.h"



//#define _Ena_drv PB10
//#define _Dis_drv PB12
//#define disable_HW_OVP_OUT PB11 // Conflict with timer use PB11
//#define PWM_FANS PA10
//#define  Flip_feedback PB0


/*
Outputs:
TIM1_CH2 → PA9  
TIM1_CH2N → PB14 

Dead time resolution:
With Fclk = 72 MHz → 1 step ≈ 13.888 ns
DTG = 4 → ~55.6 ns
DTG = 5 → ~69.4 ns
DTG = 6 → ~83.3 ns
*/

static inline void __attribute__((always_inline)) reset_flip_flop(){
// reset flip flop
GPIOB->BSRR = (1U << 10);// Ena_drv HIGH 
delayMicroseconds(10); 
GPIOB->BSRR = (1U << 26);// Ena_drv LOW
delayMicroseconds(10); 
GPIOB->BSRR = (1U << 10);// Ena_drv HIGH 
delayMicroseconds(10);
}


static inline uint16_t adc_read(uint8_t ch) {
ADC1->SQR1 = 0;                 // 1 conversion
ADC1->SQR3 = (ch & 0x1F);       // select channel 0..17
ADC1->CR2  |= ADC_CR2_SWSTART;  // start
while (!(ADC1->SR & ADC_SR_EOC));
return ADC1->DR;                // 12-bit (right-aligned)
}

static inline void __attribute__((always_inline)) init_ADC(){
// Clocks
RCC->APB2ENR |= RCC_APB2ENR_IOPAEN | RCC_APB2ENR_ADC1EN;

// PA0..PA7 analog
GPIOA->CRL = 0x00000000;

// ADC clk = PCLK2/6 (~12 MHz if PCLK2=72 MHz)
RCC->CFGR &= ~RCC_CFGR_ADCPRE;
RCC->CFGR |=  RCC_CFGR_ADCPRE_DIV6;

// Fastest sampling (1.5 cycles). Increase if source impedance is high.
ADC1->SMPR2 = 0x00000000;

// Power on -> reset cal -> calibrate
ADC1->CR2 |= ADC_CR2_ADON;
ADC1->CR2 |= ADC_CR2_RSTCAL; while (ADC1->CR2 & ADC_CR2_RSTCAL);
ADC1->CR2 |= ADC_CR2_CAL;    while (ADC1->CR2 & ADC_CR2_CAL);

// Single conversion via SWSTART (F1 needs EXTTRIG + EXTSEL=111)
ADC1->CR2 &= ~ADC_CR2_CONT;
ADC1->CR2 &= ~ADC_CR2_EXTSEL;
ADC1->CR2 |=  ADC_CR2_EXTSEL;     // set EXTSEL=111 (SWSTART)
ADC1->CR2 |=  ADC_CR2_EXTTRIG;

// Mandatory second ADON after calibration
ADC1->CR2 |= ADC_CR2_ADON;





}


static inline void __attribute__((always_inline)) init_PWM(){
// Enable clocks
RCC->APB2ENR |= RCC_APB2ENR_IOPAEN | RCC_APB2ENR_IOPBEN | RCC_APB2ENR_AFIOEN | RCC_APB2ENR_TIM1EN;

// GPIOA PA9 -> AF Push-Pull 50 MHz (PA9 is CRH nibble 1, shift 4)
GPIOA->CRH &= ~(0xF << 4);
GPIOA->CRH |= (0xB << 4);

// GPIOB PB14 -> AF Push-Pull 50 MHz (PB14 is CRH nibble 6, shift 24)
GPIOB->CRH &= ~(0xF << ((14-8)*4));
GPIOB->CRH |= (0xB << ((14-8)*4));

// Timer base config
TIM1->PSC = 0;
TIM1->ARR = 480;    // 150 kHz (edge-aligned): f = 72MHz / (PSC+1) / (ARR+1)
TIM1->CCR2 = 240;    // 50% duty (CHANGED to CCR2)

// PWM mode 1 + preload (CHANGED to OC2M and OC2PE)
TIM1->CCMR1 |= (6 << TIM_CCMR1_OC2M_Pos) | TIM_CCMR1_OC2PE; // OC2M=110 (PWM1), preload
TIM1->CR1  |= TIM_CR1_ARPE;                // ARR preload

// Enable CH2 + CH2N (CHANGED to CC2E and CC2NE)
//TIM1->CCER |= TIM_CCER_CC2E | TIM_CCER_CC2NE;
// Explicitly ensure outputs are disabled to guarantee starting low
TIM1->CCER &= ~(TIM_CCER_CC2E | TIM_CCER_CC2NE);


/*

Dead time resolution:
With Fclk = 72 MHz → 1 step ≈ 13.888 ns
DTG = 4 → 55.6 ns
DTG = 5 → 69.4 ns
DTG = 6 → 83.3 ns
DTG = 7 → 97.2 ns
DTG = 10 → 138.9 ns
DTG = 15 → 208.3 ns
DTG = 20 → 277.8 ns
*/
// Dead-time (~70 ns) + MOE
TIM1->BDTR = (20 << TIM_BDTR_DTG_Pos) | TIM_BDTR_MOE;

// Force update to load preloaded regs initially
TIM1->EGR = TIM_EGR_UG;

// Start counter
TIM1->CR1 |= TIM_CR1_CEN;

// Only overflow/underflow generate UEV (ignore UG for IRQ/DMA)—keeps latching clean
TIM1->CR1 |= TIM_CR1_URS;

// === A1 marker pin: PA1 as push-pull 50 MHz ===
/*RCC->APB2ENR |= RCC_APB2ENR_IOPAEN;
GPIOA->CRL &= ~(GPIO_CRL_MODE1 | GPIO_CRL_CNF1);
GPIOA->CRL |= (0b11 << GPIO_CRL_MODE1_Pos); // MODE1=11 (50 MHz), CNF1=00 (PP)
*/
// Clear any pending UIF from the initial UG so first sync waits properly
TIM1->SR &= ~TIM_SR_UIF;







}




static inline void __attribute__((always_inline))  init_digital_pins() {
// **_Ena_drv (PB10)** as output 
GPIOB->CRH &= ~(0xF << 8); 
GPIOB->CRH |= (0x3 << 8);



// Flip_feedback as input 
// 2. Erase PB0 bits, leave PB1-PB7 untouched
GPIOB->CRL &= ~(0xF << 0); 
// 3. Write 0x4 (Floating Input) to PB0
GPIOB->CRL |= (0x4 << 0);

/*
//_Dis_drv (PB12)	OUTPUT OPEN DRIVE
GPIOB->CRH &= ~(0xF << 16); GPIOB->CRH |= (0x7 << 16);
GPIOB->BSRR = (1U << 12);//_Dis_drv  =HIGH = OPEN 
*/


//disable_HW_OVP_OUT (PB11)	OUTPUT
GPIOB->CRH &= ~(0xF << 12); GPIOB->CRH |= (0x3 << 12);
GPIOB->BSRR = (1U << 11);//disable_HW_OVP_OUT (PB11) HEIGH 



/*
// PB1 AS INPUT (COMP FEEDBACK)
// 1. Clear exactly 4 bits for PB1 (bits 4, 5, 6, 7)
// PB0, PB2-PB7 remain exactly as they were.
GPIOB->CRL &= ~(0xF << 4); 
// 2. Set PB1 to Floating Input (0x4)
GPIOB->CRL |= (0x4 << 4);
*/

// PWM_FANS (PA10)	OUTPUT	 
GPIOA->CRH &= ~(0xF << 8); GPIOA->CRH |= (0x3 << 8);
// TURN FAN ON HIGH 
GPIOA->BSRR = (1U << 10);
}


void setup() {
init_PWM();
analogReadResolution(12);
init_ADC();  
init_digital_pins();
reset_flip_flop();
}




// Function updated to handle CCR2
static inline void pwm_periode_dutyc_free_glitch(uint16_t arr, uint16_t ccr2) // FUNCTION NAME CHANGED and uses ccr2
{
// --- Critical ordering to avoid the race ---
uint32_t prim = __get_PRIMASK(); __disable_irq();
TIM1->CR1 |= TIM_CR1_UDIS;   // 1) Block update transfers (no latching while we stage)
TIM1->SR &= ~TIM_SR_UIF;    // 2) Clear UIF *after* blocking updates (so we wait for the next real UEV)
//TIM1->ARR = arr;        // 3) Stage ARR
TIM1->ARR = arr - 1;
TIM1->CCR2 = ccr2;       // 3) Stage CCR2 (e.g., (arr+1)/2 for 50%)
TIM1->CR1 &= ~TIM_CR1_UDIS;   // 4) Re-enable update transfers
if (!prim) __enable_irq();

// 5) Wait for the *next* UEV — this is when ARR/CCR2 actually latch
while (!(TIM1->SR & TIM_SR_UIF)) { /* wait for latch boundary */ }
TIM1->SR &= ~TIM_SR_UIF;    // acknowledge

// 6) Mark the latching instant on A1 (few CPU cycles after boundary)
//toggle_A1_fast();


}






// Global variables

int min_periode = (int) 480; //72E3/150=480 , 150 kHz
int max_periode = (int) 758;  //72E3/95=757.89, 95khz


float per_accumulator = (float)  min_periode; //480.0
unsigned long last_time_us = 0;
const float SLEW_RATE_TICKS_PER_US =0.72; //277.89/386 =0.72, (277 ticks / 386us)


float vout=0;
float vin=0;
int Periode, Periode__; 










static inline void __attribute__((always_inline))  soft_start_protocol(){




//================== wait validat voltage to start ======
int Vin_Min_to_start = 60;
float Vinold = -100;
float Vindiff=100; 
delay (10);
while(vin<Vin_Min_to_start || Vindiff >10  )
{//START AT 100V min 
//the loop will exit only when vin >= 60 AND Vindiff <= 10
vin=0.3212 * adc_read(7) - 7.2289;
Vindiff = vin -Vinold;
Vinold = vin ; 
if (Vindiff < 0) Vindiff =-Vindiff ; // Abs
delay (1);
};
delay (10);
//=======================================================





//Periode = min_periode;//= 480 ticks = 150kHz 
Periode =288; //72Mhz/250khz=288
pwm_periode_dutyc_free_glitch(Periode, Periode / 2);

// Charge the boostrap capa 
// 1. Enable PA9 (Main channel / Low-Side)
TIM1->CCER |= TIM_CCER_CC2E;  
// 2. Disable PB14 (Complementary channel / High-Side)
TIM1->CCER &= ~TIM_CCER_CC2NE;
delayMicroseconds(100);




/*
Dead time resolution:
With Fclk = 72 MHz → 1 step ≈ 13.888 ns
DTG = 4 → 55.6 ns
DTG = 50 → 694.4 ns
DTG = 10 → 138.9 ns
*/
TIM1->BDTR = (50<< TIM_BDTR_DTG_Pos) | TIM_BDTR_MOE;


//Periode = 686;//105kHz 
//pwm_periode_dutyc_free_glitch(Periode, Periode / 3);
// Enable CH2 + CH2N (CHANGED to CC2E and CC2NE)
TIM1->CCER |= TIM_CCER_CC2E | TIM_CCER_CC2NE;
//delayMicroseconds(100);
while (Periode < 480){ // (480-288)=192x 10u = 1.92ms
//72e6/150e3=480
delayMicroseconds(10);
pwm_periode_dutyc_free_glitch(Periode, Periode / 2);
Periode = Periode +2;
}


// Change dead time to 140ns 
TIM1->BDTR = (10 << TIM_BDTR_DTG_Pos) | TIM_BDTR_MOE;
delayMicroseconds(100);




}







static inline void __attribute__((always_inline)) activated_HWP_VOUT(){
// Enable the Vout HW OVP: MAKE OVP_INPUT (PB11) AS INPUT
GPIOB->CRH &= ~(0xF << 12); GPIOB->CRH |= (0x4 << 12);
}






//////////////////////////// TEMP FUNCTION /////////////////////
const int TABLE_SIZE = 15;

const float fac[TABLE_SIZE] = {
  0.53021892, 0.7085381, 0.96818072, 1.38331188,
  1.93285179, 2.73708445, 4.08904919, 6.24657131,
  9.97772497, 15.24231371, 26.6183813, 44.06236682,
  67.31117763, 87.96500807, 189.44444201
};

const float temp[TABLE_SIZE] = {
  125.0, 112.03703704, 100.07122507, 85.61253561,
  74.14529915, 62.67806268, 50.21367521, 37.74928775,
  24.78632479, 13.81766382, 0.35612536, -11.11111111,
  -20.08547009, -25.56980057, -40.02849003
};
float interpolate1D(float x) {

  // Clamp below range
  if (x <= fac[0]) {
    return temp[0];
  }

  // Clamp above range
  if (x >= fac[TABLE_SIZE - 1]) {
    return temp[TABLE_SIZE - 1];
  }

  // Find interval
  for (int i = 0; i < TABLE_SIZE - 1; i++) {
    if (x >= fac[i] && x <= fac[i + 1]) {

      float x0 = fac[i];
      float x1 = fac[i + 1];
      float y0 = temp[i];
      float y1 = temp[i + 1];

      // Linear interpolation formula
      return y0 + (x - x0) * (y1 - y0) / (x1 - x0);
    }
  }

  return 0; // Should never reach here
}
float temp_secondary(){
uint16_t a6 = adc_read(6);
int ADCMAX = 4096; 
float vcc= 3.328;
float R_2 = 4.99; 
float A6V, RthS;  
A6V= vcc*a6/ADCMAX ; 
RthS= R_2/(vcc/A6V-1); 
return interpolate1D(RthS);
}
float temp_primary(){
uint16_t a6 = adc_read(2);
int ADCMAX = 4096; 
float vcc= 3.328;
float R_2 = 35.5987 ; //35.1294; 
float A2V, RthS;  
A2V= vcc*a6/ADCMAX ; 
RthS= R_2/(vcc/A2V-1); 
return interpolate1D(RthS);
}
/////////////////////////////////////////////////////////





///////////////////////////////////////////////////////
float  temp_power_derating(float Temp){
float T0_der=60;
float T1_der=90;
float P_nom= 1200*1.05;//5% of margin vs specification 
if (Temp < T0_der) return P_nom; 
if (Temp >=  T0_der && Temp <=  T1_der){
//float x_val = 
// =+(D12-60)/(90-60)
//=1200*(1-L12)
 return  P_nom*(1-(Temp-T0_der)/(T1_der-T0_der)); 
}
if (Temp > T1_der) return 0; 
}
///////////////////////////////////////////////////////
float Power_derat_prim_second(){
  float tempS= temp_secondary(); 
  //Serial.print(tempS); Serial.print(' ');
  float tempP=temp_primary(); 
  //Serial.print(tempP); Serial.print(' ');
  // Max temp
  if (tempP> tempS) tempS = tempP; 
  return temp_power_derating( tempS);
}
void loop() {

  soft_start_protocol();
  activated_HWP_VOUT();
  unsigned long step_delay;
  float error , Power ,  Power_derating, Iout, Iin; 

  // ── Tuning ──────────────────────────────────────────────
  const float vout_target     = 48.0f;
  const float DEADBAND        = 0.15f;  // [V]  no step inside this window
  const int   TICK_STEP       = 2;     // [ticks] always 2, ZVS safe
  const unsigned long DLY_FAR  =  20;  // [µs] |error| > 2.0V
  const unsigned long DLY_MID  = 100;  // [µs] |error| > 0.5V
  const unsigned long DLY_NEAR = 400;  // [µs] |error| > 0.1V  ← key for stability
  // ────────────────────────────────────────────────────────

  unsigned long step_timer = micros();

  while (1) {

    // ── FAST PATH: always runs, no blocking ──────────────
    // READ INPUTS 
    vout = 0.03081f * adc_read(1) - 0.09761f;
    vin=0.3212 * adc_read(7) - 7.2289;
    Iout = 0.016064*(adc_read(0)-412) ; //se excel file 
    Iin = 0.002008*(adc_read(5)-197) ; //se excel file


    error = vout_target - vout;
    if (error < 0) error = -error;  // ABS function 
    // Determine step delay from current error zone
    if      (error > 1.0f) step_delay = DLY_FAR;
    else if (error > 0.3f) step_delay = DLY_MID;
    else                   step_delay = DLY_NEAR;


    // PowerDerating
    Power = vout*Iout; 
    Power_derating= Power_derat_prim_second(); // Watt

    // ── SLOW PATH: step only when timer expired + outside deadband ──
    if (((error > DEADBAND)||(Power > Power_derating)) && (micros() - step_timer) >= step_delay) {

      step_timer = micros();  // reset timer BEFORE pwm call (pwm blocks ~7µs)

      if (Power > Power_derating){
        Periode -= TICK_STEP; // Periode decrease → raise freq → less gain → vlow 
      }
      else {
        if (vout < vout_target) {
          Periode += TICK_STEP; // Vout too low  → lower freq → more gain
        } else {
          Periode -= TICK_STEP; // Vout too high → raise freq → less gain
        }
      }

      // Safety clamp
      if (Periode > max_periode) Periode = max_periode;
      if (Periode < min_periode) Periode = min_periode;

      // Force even value (half-bridge symmetry)
      Periode = (Periode / 2) * 2;

      // Apply — blocks until UEV boundary (~7µs), called ONLY here
      pwm_periode_dutyc_free_glitch(Periode, Periode / 2);
    }

  }
}

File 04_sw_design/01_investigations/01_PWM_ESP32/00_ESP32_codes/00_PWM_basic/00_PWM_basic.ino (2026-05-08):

// This code sets up two MCPWM timers on the ESP32 to generate complementary PWM signals
// with configurable dead time and duty cycle, suitable for power electronics applications.

#include "arduino.h" // Include the Arduino core library
#include "driver/mcpwm.h" // Include the MCPWM driver for advanced PWM control
#include "soc/mcpwm_reg.h" // Include register-level definitions for MCPWM
#include "soc/mcpwm_struct.h" // Include MCPWM structure definitions

#define GPIO_PWM0A_OUT 13   // Define GPIO 13 as output for MCPWM0A (High side)==> CH1
#define GPIO_PWM0B_OUT 12   // Define GPIO 12 as output for MCPWM0B (Low side) ==> CH2

int frequency = 200000; // Set desired PWM frequency Hz

float dutyCycleA = 50; // Set duty cycle for Timer 0 in %
//float dutyCycleB = 25; // Set duty cycle for Timer 1 %
// not working, in complimentary i must give only one duty cycle 
// the other is calculated as 100% - first DD - dead time 
int deadTime_ns = 20; // Set dead time nanoseconds

int resolution_Mhz = 160; // Set clock resolution to 160 MHz
int deadTime_ticks = deadTime_ns / (1000 / resolution_Mhz); // Convert dead time from ns to clock ticks

void MCPWM_SetUP() { // Function to configure MCPWM settings


  mcpwm_group_set_resolution(MCPWM_UNIT_0, 1000000 * resolution_Mhz); // Set MCPWM group resolution
  mcpwm_timer_set_resolution(MCPWM_UNIT_0, MCPWM_TIMER_0, 1000000 * resolution_Mhz); // Set resolution for Timer 0
  mcpwm_timer_set_resolution(MCPWM_UNIT_0, MCPWM_TIMER_1, 1000000 * resolution_Mhz); // Set resolution for Timer 1

  mcpwm_config_t pwm_config; // Create MCPWM config structure
  pwm_config.frequency = frequency; // Assign frequency to config
  pwm_config.cmpr_a = 0; // Initial duty cycle A set to 0%
  pwm_config.cmpr_b = 0; // Initial duty cycle B set to 0%
  pwm_config.counter_mode = MCPWM_UP_COUNTER; // Use up-counting mode
  pwm_config.duty_mode = MCPWM_DUTY_MODE_0; // Set duty mode to active high

  mcpwm_init(MCPWM_UNIT_0, MCPWM_TIMER_0, &pwm_config); // Initialize Timer 0 with config
  mcpwm_init(MCPWM_UNIT_0, MCPWM_TIMER_1, &pwm_config); // Initialize Timer 1 with config

  mcpwm_set_timer_sync_output(MCPWM_UNIT_0, MCPWM_TIMER_0, MCPWM_SWSYNC_SOURCE_TEZ); // Configure sync output on TEZ (timer event zero)

  mcpwm_deadtime_enable(MCPWM_UNIT_0, MCPWM_TIMER_0, MCPWM_ACTIVE_HIGH_COMPLIMENT_MODE, deadTime_ticks, deadTime_ticks); // Enable dead time for Timer 0
  mcpwm_deadtime_enable(MCPWM_UNIT_0, MCPWM_TIMER_1, MCPWM_ACTIVE_HIGH_COMPLIMENT_MODE, deadTime_ticks, deadTime_ticks); // Enable dead time for Timer 1

  mcpwm_set_duty(MCPWM_UNIT_0, MCPWM_TIMER_0, MCPWM_GEN_A, dutyCycleA); // Set duty cycle for Timer 0 Generator A
  //mcpwm_set_duty(MCPWM_UNIT_0, MCPWM_TIMER_1, MCPWM_GEN_A, dutyCycleB); // Set duty cycle for Timer 1 Generator A

  mcpwm_gpio_init(MCPWM_UNIT_0, MCPWM0A, GPIO_PWM0A_OUT); // Assign GPIO 13 to MCPWM0A
  mcpwm_gpio_init(MCPWM_UNIT_0, MCPWM0B, GPIO_PWM0B_OUT); // Assign GPIO 12 to MCPWM0B
}

void setup() { 
  MCPWM_SetUP(); // Call MCPWM setup during startup
}

void loop() { 
} // Empty loop since PWM runs independently

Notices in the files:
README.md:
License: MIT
